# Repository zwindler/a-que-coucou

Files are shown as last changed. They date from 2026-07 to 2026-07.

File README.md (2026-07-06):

# À que coucou !

> Une boîte à coucou qui détecte l'expression **"ah que coucou"** grâce à un modèle de wake word, actionne un servomoteur pour faire sortir un œuf, et joue le son "coucou !".

Inspirée du running gag des [Guignols de l'info](https://www.youtube.com/watch?v=vwc_aIZz_1g) où Johnny Hallyday présentait une boîte mystérieuse à PPDA.

## Principe

1. Un microphone écoute en permanence l'environnement sonore
2. Quand la phrase **"ah que coucou"** est détectée, la boîte se déclenche
3. Un œuf monte mécaniquement hors de la boîte via un pignon-crémaillère
4. Le son *"coucou !"* est joué via un haut-parleur
5. L'œuf redescend après quelques secondes

Le tout fonctionne de manière autonome sur un Raspberry Pi, sans connexion internet, avec une latence inférieure à 500ms.

## Matériel

| Composant | Usage |
|---|---|
| Raspberry Pi 5 | Plateforme principale |
| Servo TowerPro SG90 (GPIO13 PWM) | Actionne l'œuf |
| Micro INMP441 I2S | Capture audio |
| Ampli MAX98357A I2S | Sortie audio |
| Haut-parleur 4Ω 3W | Diffusion sonore |
| Boîte + œuf imprimés en 3D | Habillage et mécanisme |
| Breadboard 170pts | Partage bus I2S |
| Câbles Dupont F-F et M-F | Câblage |

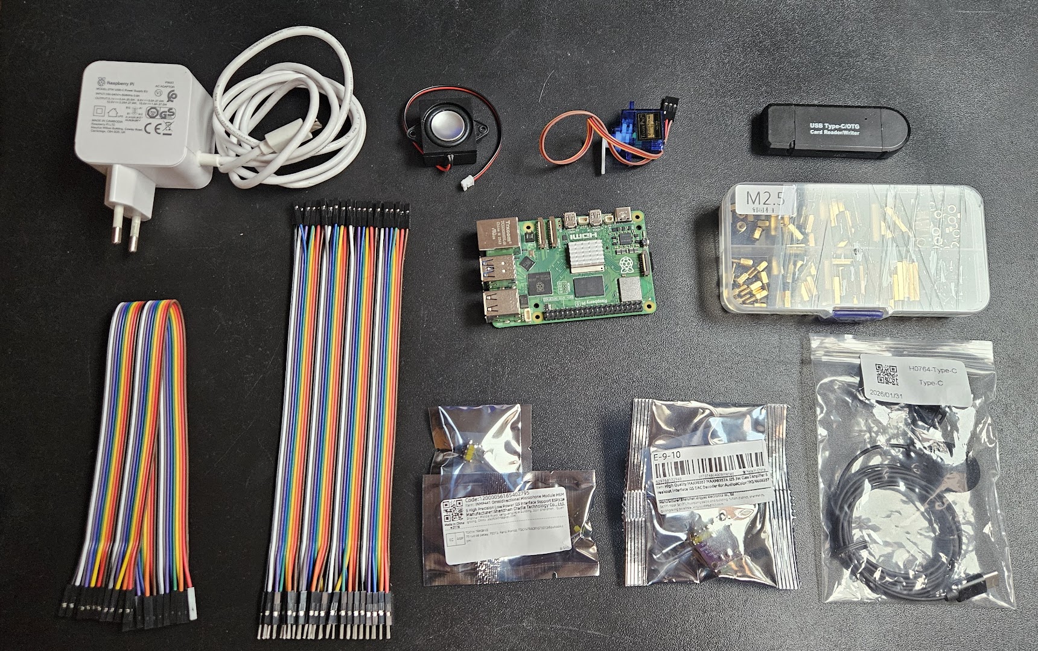
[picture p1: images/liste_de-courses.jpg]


Coût total du projet : **30-40 €** (hors RPi 5 & imprimante 3D).

## Architecture

```
aquecoucou.py           # Orchestrateur : détection -> servo -> son
wakeword.py             # Module de détection openWakeWord
├── setup.sh            # Installation complète RPi (apt, pip, config.txt, systemd)
├── deploy.sh           # Déploiement vers le RPi (tar + ssh)
└── deploy/
    └── aquecoucou.service  # Unité systemd (démarrage automatique)

tests/                  # Scripts de diagnostic
├── test_servo.py       # Test servo SG90
├── test_audio.py       # Test lecture WAV
├── test_wakeword.py    # Test détection en temps réel (affichage scores)
└── test_mic.py         # Diagnostic micro (analyse RMS, static noise)

wakeword/               # Pipeline d'entraînement
├── train_wakeword.py   # Entraînement modèle openWakeWord
├── generate_tts.py     # Génération voix synthétiques (Coqui TTS)
├── Containerfile       # Container TTS
├── Containerfile.train # Container entraînement
└── output/             # Modèle ONNX entraîné

cad/                    # CAO (OpenSCAD)
├── base.scad / .stl    # Base de la boîte
├── box.scad / .stl     # Murs de la boîte
├── pinion.scad / .stl  # Pignon 40mm (axe SG90)
├── rack.scad / .stl    # Crémaillère 110mm
├── egg.scad / .stl     # Œuf
├── rail_bracket.scad / .stl  # Rail + support servo
└── aquecoucou.3mf      # Projet d'assemblage pour mon imprimante Bambu Labs

sounds/
└── boite_a_coucou.wav  # Son "coucou !" (à fournir, voir sounds/README.md)

images/                 # Photos et captures d'écran
```

## Câblage

Tout se branche sur le header GPIO 40 broches du Raspberry Pi 5. Les composants audio (micro + ampli) partagent le même bus I2S ; le servo est piloté en PWM matériel sur GPIO13.

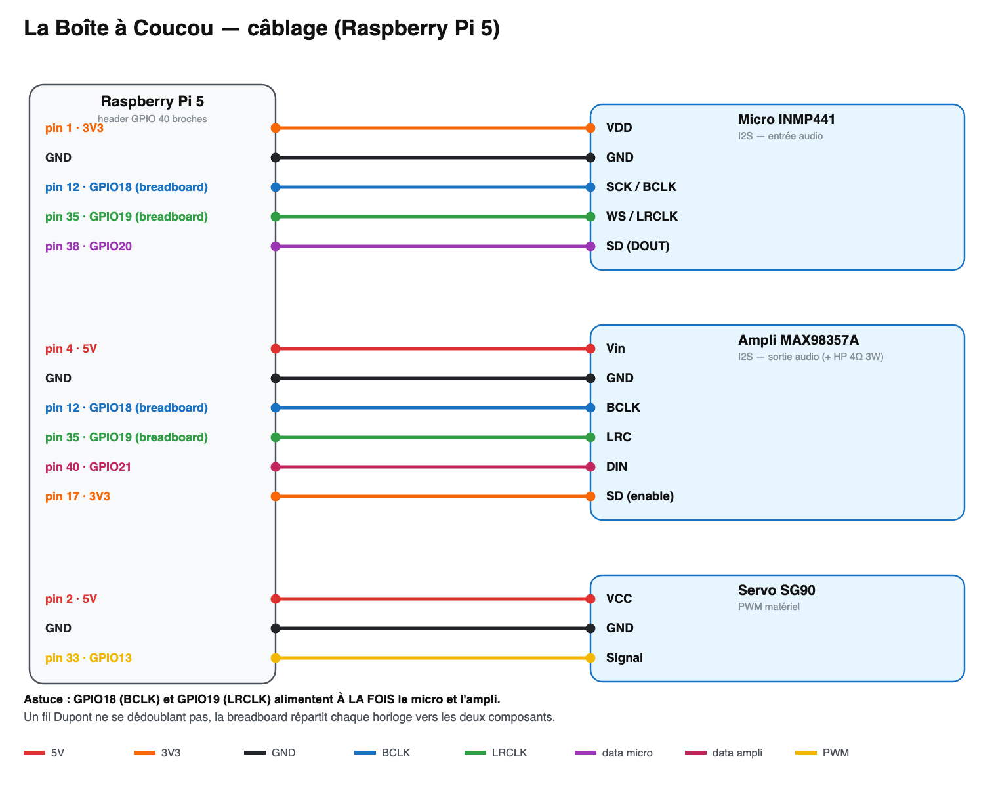
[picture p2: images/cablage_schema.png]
Schéma de câblage


Et la position physique des broches sur le header (pour ne pas se tromper au branchement) :

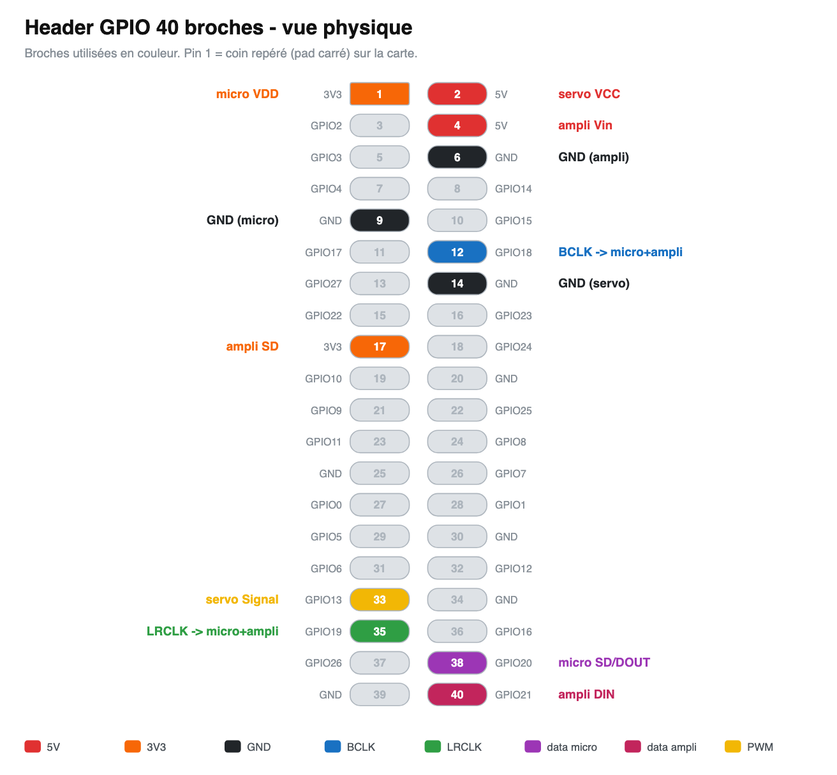
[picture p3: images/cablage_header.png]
Header GPIO 40 broches - broches utilisées en couleur


Le détail broche par broche (à cocher pendant le branchement) :

| Composant | Broche | Broche RPi |
|---|---|---|
| **Servo SG90** | VCC | 5V (broche 2) |
| | GND | GND (broche 14) |
| | Signal | GPIO13 / PWM (broche 33) |
| **Micro INMP441** (I2S) | VDD | 3.3V (broche 1) |
| | GND | GND (broche 9) |
| | SCK (BCLK) | GPIO18 (broche 12), via breadboard |
| | WS (LRCLK) | GPIO19 (broche 35), via breadboard |
| | SD (DOUT) | GPIO20 (broche 38) |
| **Ampli MAX98357A** (I2S) | Vin | 5V (broche 4) |
| | GND | GND (broche 6) |
| | BCLK | GPIO18 (broche 12), via breadboard |
| | LRC | GPIO19 (broche 35), via breadboard |
| | DIN | GPIO21 (broche 40) |
| | SD | 3.3V (broche 17), pour activer la sortie |
| | Speaker + / - | Haut-parleur 4Ω 3W |

Si votre module INMP441 a une broche `L/R`, reliez-la à GND (canal gauche).

**Le point important** : les deux horloges I2S, BCLK (GPIO18) et LRCLK (GPIO19), doivent être reliées **à la fois** au micro et à l'ampli. Un câble Dupont ne se dédoublant pas, on passe par la breadboard pour répartir chacune de ces deux lignes vers les deux composants.

Les overlays nécessaires (`googlevoicehat-soundcard` pour l'I2S et `pwm-2chan` pour le servo) sont ajoutés dans `/boot/firmware/config.txt` par `setup.sh`.

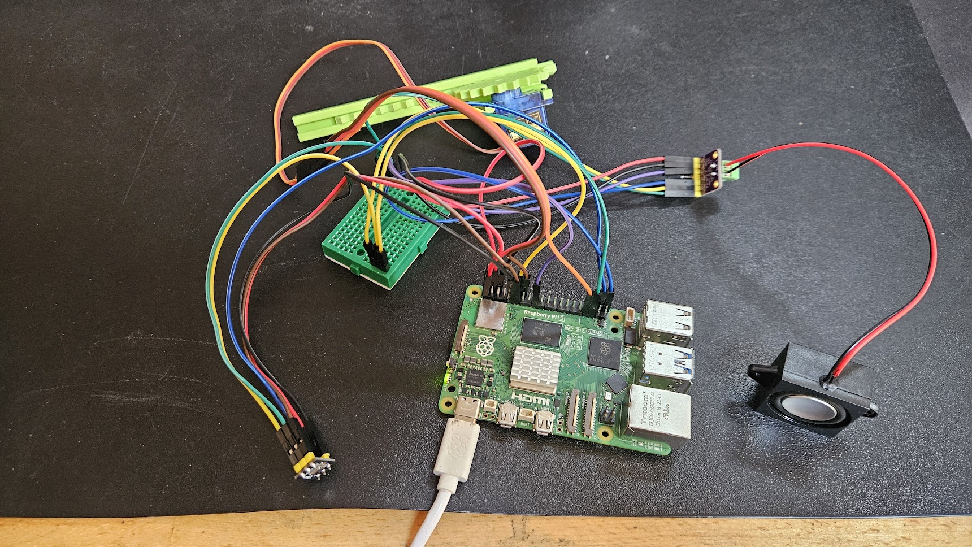
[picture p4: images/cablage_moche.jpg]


## Mécanisme (pignon-crémaillère)

Le servo ne fait qu'un mouvement semi-circulaire ; pour faire sortir l'œuf **tout droit**, un pignon fixé sur son axe entraîne une crémaillère, convertissant la rotation en translation verticale. Les pièces sont paramétriques en OpenSCAD (`cad/pinion.scad`, `cad/rack.scad`).

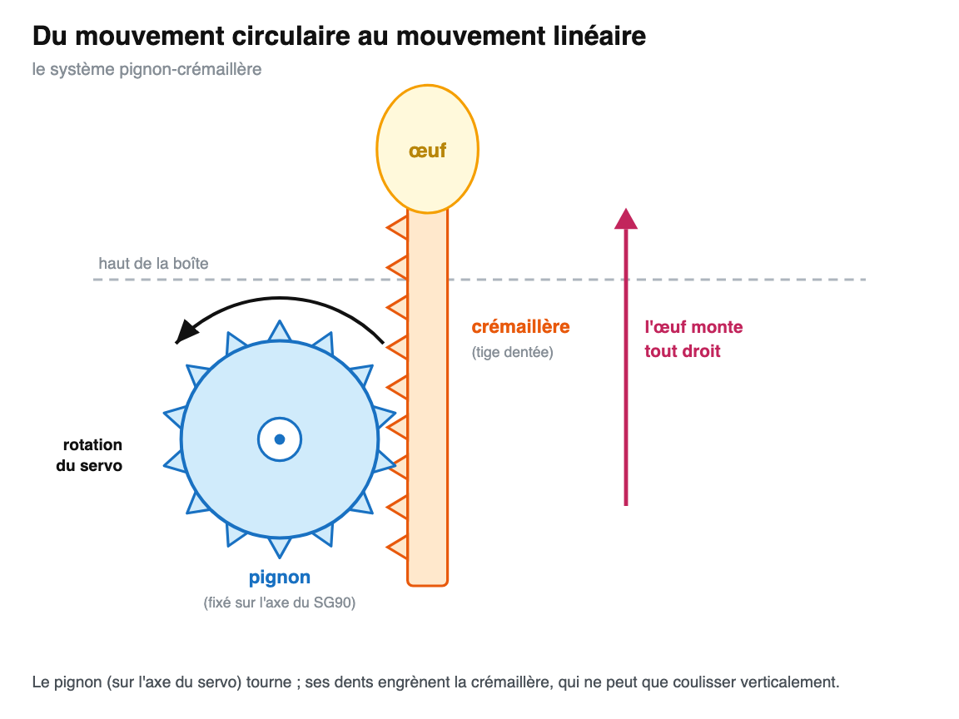
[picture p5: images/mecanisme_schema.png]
Principe pignon-crémaillère : la rotation du servo est convertie en montée verticale de l'œuf


## Installation

```bash
# Sur le Raspberry Pi, tout-en-un
./setup.sh
```

`setup.sh` installe les dépendances système, crée le venv, installe les paquets Python, configure `/boot/firmware/config.txt` (désactive l'audio BCM, ajoute les overlays I2S et PWM), et installe le service systemd.

## Utilisation

```bash
python aquecoucou.py [--device 0] [--threshold 0.3] [--cooldown 5] [--model chemin]
```

Le service systemd démarre automatiquement au boot. Déployer une nouvelle version :

```bash
./deploy.sh pi@raspberrypi.local
```

## Entraînement du modèle

Le modèle de wake word "ah que coucou" est entraîné à partir de voix synthétiques générées par Coqui TTS (XTTS v2), avec augmentation audio et exemples négatifs.

En amont, chaque extrait sonore est transformé en mel-spectrogramme (représentation temps-fréquence) avant d'alimenter le modèle :

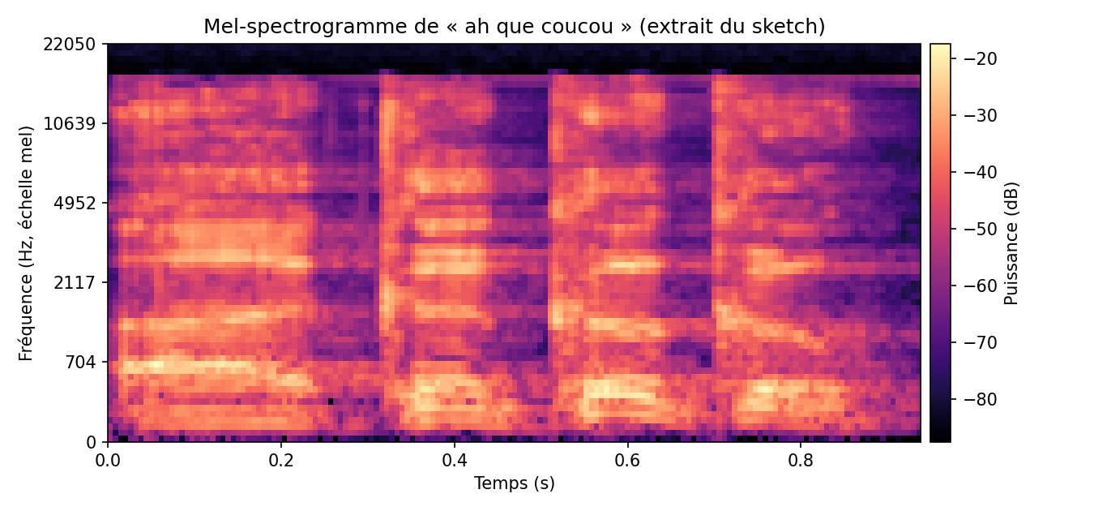
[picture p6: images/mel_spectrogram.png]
Mel-spectrogramme de « ah que coucou »


```bash
# Génération des voix TTS (nécessite GPU)
cd wakeword
podman build -f Containerfile -t aquecoucou-tts .
podman run --rm --device nvidia.com/gpu=all \
  -v ./output:/app/output:z aquecoucou-tts

# Entraînement du modèle (GPU recommandé)
podman build -f Containerfile.train -t aquecoucou-train .
podman run --rm --device nvidia.com/gpu=all \
  -v ./output:/app/output:z aquecoucou-train
```

> **Note** : la génération TTS a besoin de voix de référence (fichiers WAV montés dans le conteneur via `generate_tts.py --references-dir`). Celles utilisées ici sont des voix personnelles, non distribuées avec le projet : pour régénérer les données, fournissez les vôtres. Le modèle pré-entraîné (`wakeword/output/ah_que_coucou.onnx`) est de toute façon inclus et prêt à l'emploi.

## Au-delà du code

Ce projet est né d'une idée transgénérationnelle père-fils. Le père, électronicien, devait s'occuper de la partie mécanique ; le fils (moi) de la partie logicielle. Un premier prototype fonctionnel a vu le jour en 2021 avec Snowboy, avant qu'un deuil dans la famille ne mette le projet en pause. Cinq ans plus tard, en 2026, le projet a été relancé avec les technologies actuelles : openWakeWord pour la détection, un RPi 5 comme cerveau, et une mécanique imprimée en 3D.

## Licence

MPL 2.0

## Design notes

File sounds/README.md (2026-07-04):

# Son de la boîte

Placez ici le fichier `boite_a_coucou.wav` joué au déclenchement.

Le son original du sketch des Guignols de l'info est protégé par le droit
d'auteur et n'est donc pas distribué avec ce projet. Fournissez votre propre
enregistrement (n'importe quel WAV convient, idéalement court).

Format utilisé pour le prototype : WAV 44100 Hz, 16 bits, stéréo.
Le chemin attendu par le code est `sounds/boite_a_coucou.wav`
(voir `play_sound()` dans `aquecoucou.py`).

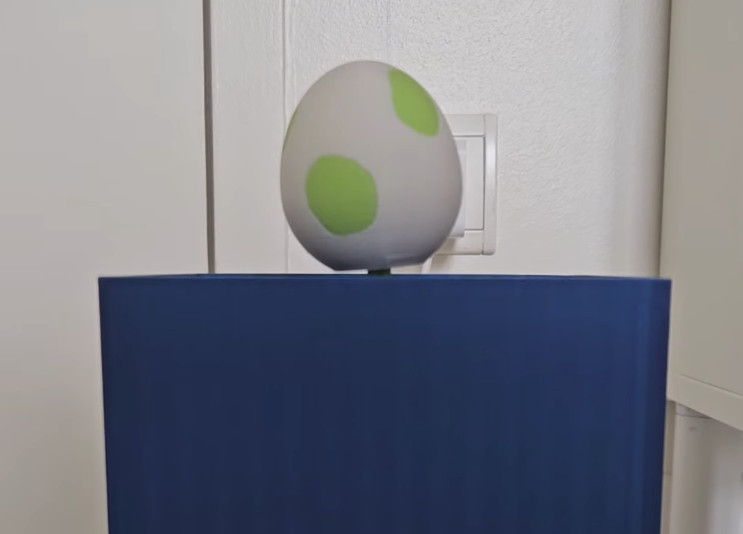
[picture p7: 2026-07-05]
images/capture_video.png

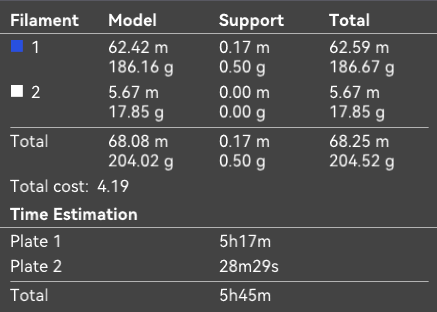
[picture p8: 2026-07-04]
images/filament_boite_coucou.png

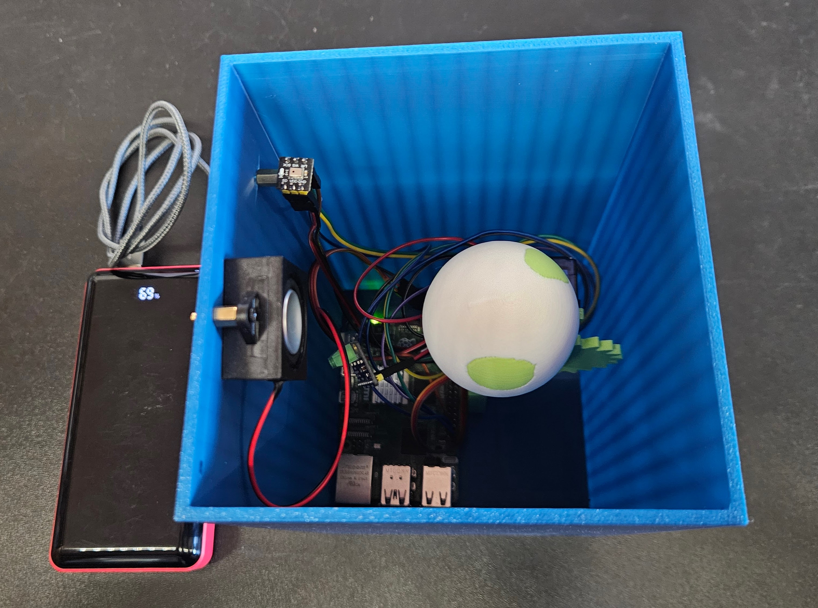
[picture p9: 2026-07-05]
images/boite_vue_den_haut.jpg

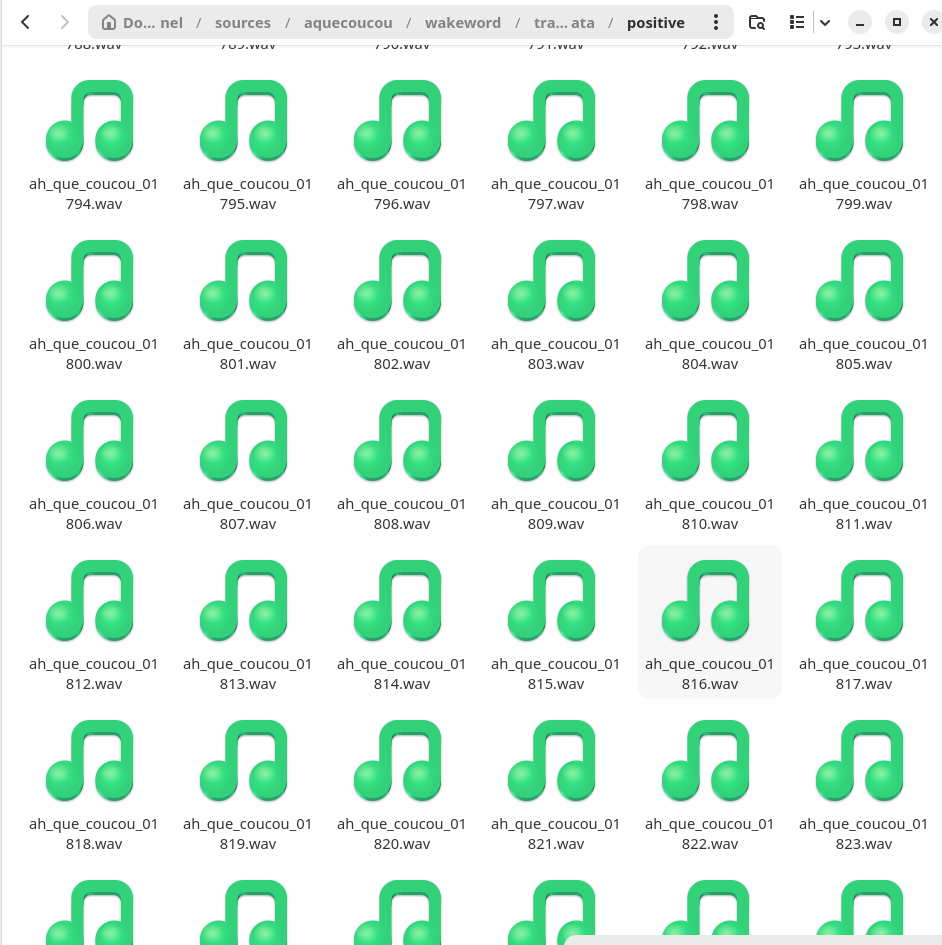
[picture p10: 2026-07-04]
images/generer_tts_aquecoucou.png

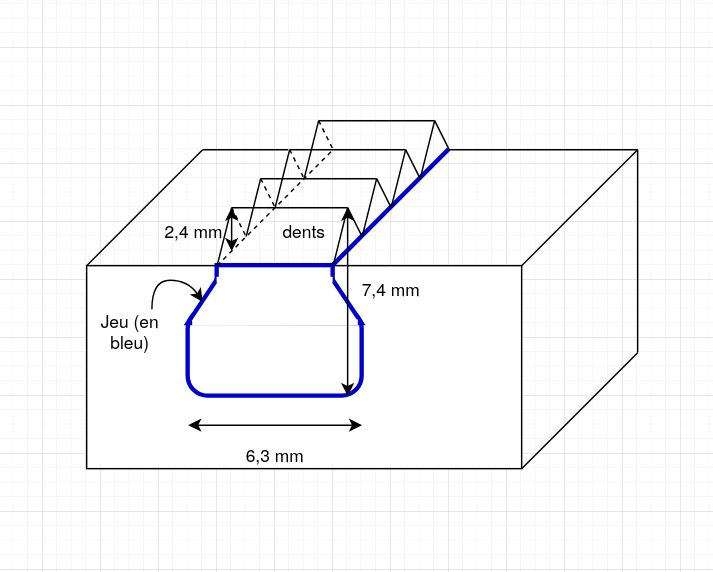
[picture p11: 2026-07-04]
images/rack.png

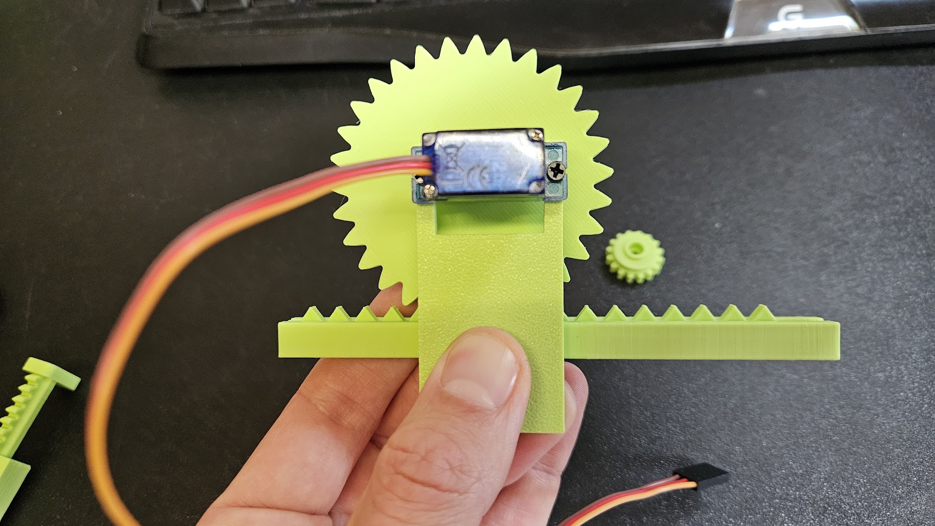
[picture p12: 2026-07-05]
images/pinion_rack.jpg

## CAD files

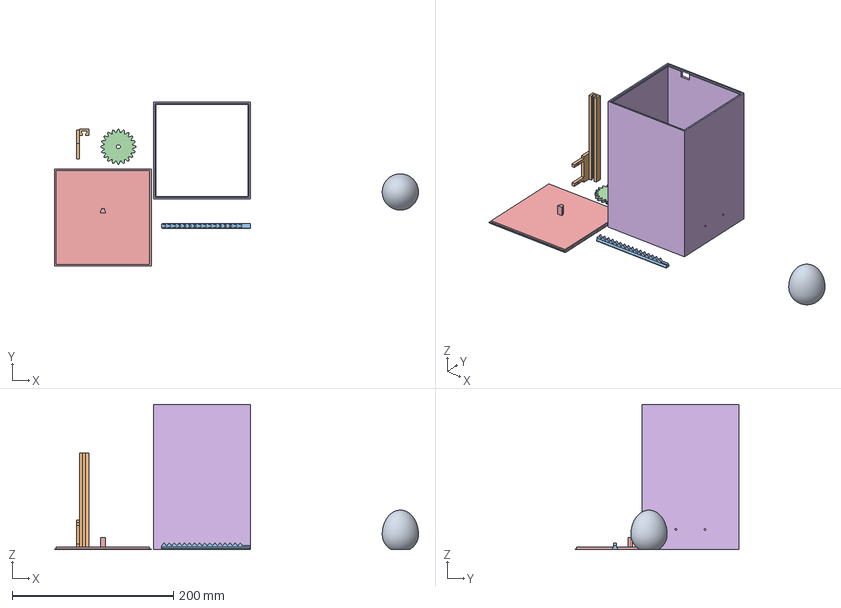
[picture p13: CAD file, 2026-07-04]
cad/aquecoucou.3mf
451.0 x 202.9 x 180.0 mm
egg.stl
rail_bracket.stl
rack.stl
pinion.stl
base.stl
box.stl

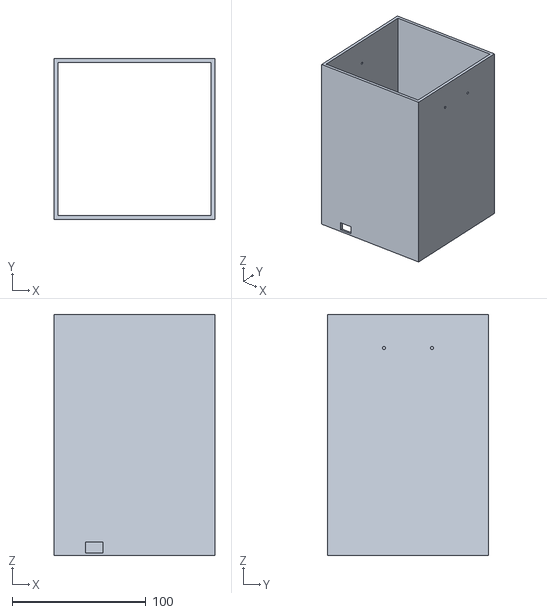
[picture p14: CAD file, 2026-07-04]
cad/box.stl
120.0 x 120.0 x 180.0

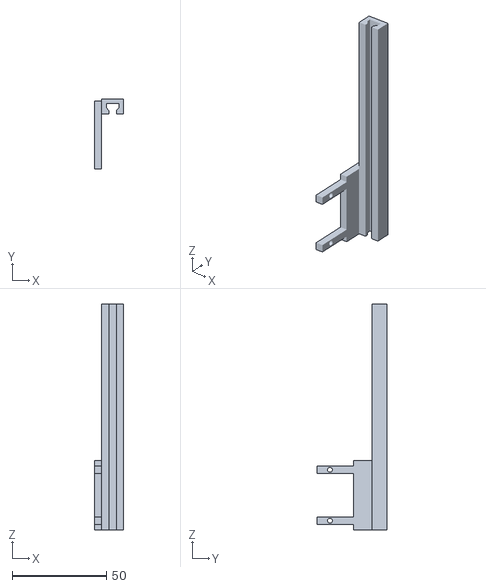
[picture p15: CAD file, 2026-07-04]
cad/rail_bracket.stl
15.6 x 37.2 x 120.0

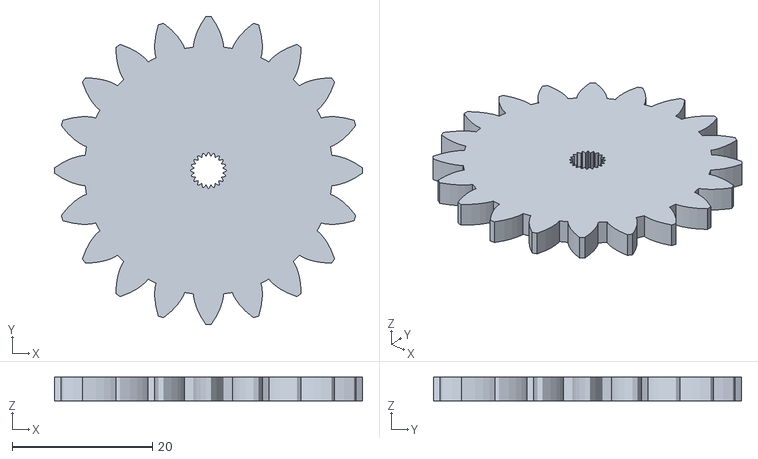
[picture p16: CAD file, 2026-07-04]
cad/pinion.stl
44.0 x 44.0 x 3.40

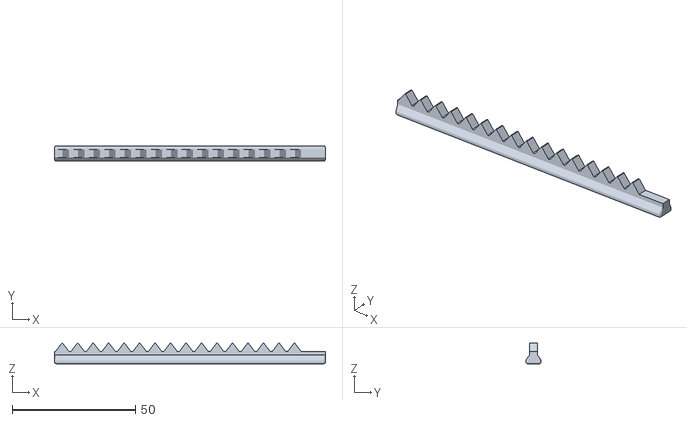
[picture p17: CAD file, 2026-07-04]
cad/rack.stl
110.0 x 6.27 x 8.39

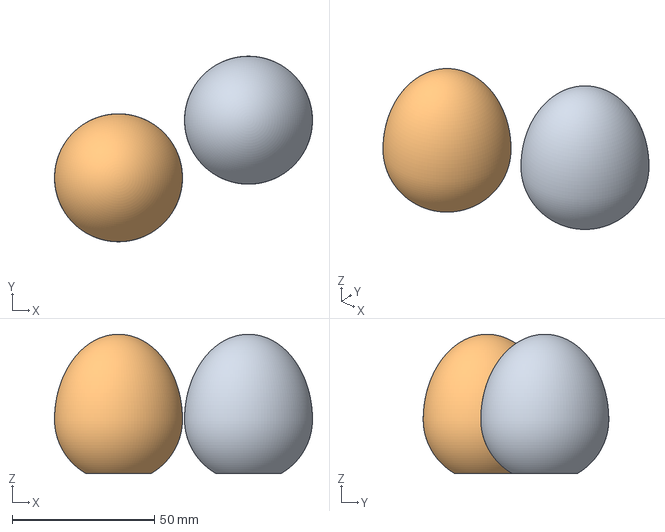
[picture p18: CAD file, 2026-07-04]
cad/egg_AMS_option.3mf
90.7 x 65.2 x 49.0 mm
egg.stl x 2

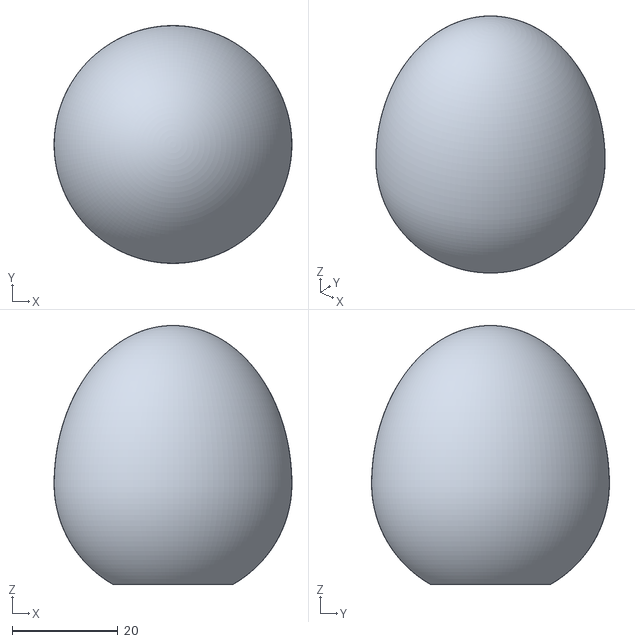
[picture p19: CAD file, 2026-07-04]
cad/egg.stl
45.0 x 45.0 x 49.0

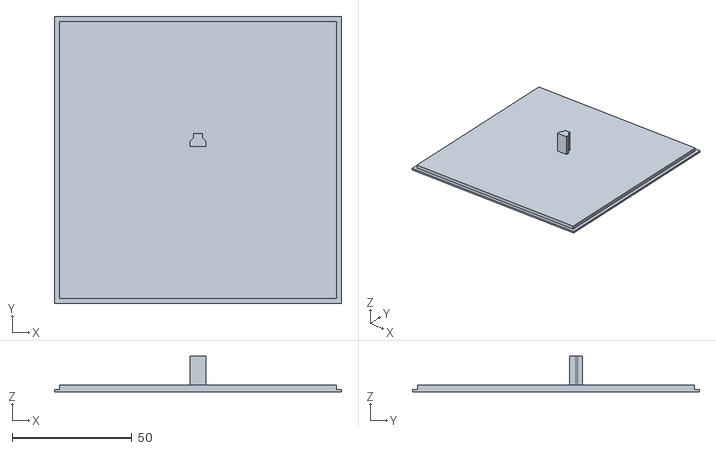
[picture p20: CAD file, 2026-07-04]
cad/base.stl
120.0 x 120.0 x 15.0

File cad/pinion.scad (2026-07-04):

// Pignon pour rack and pinion - La Boîte à Coucou
// Compatible axe SG90 spline cannelé 4.7mm
//
// Paramètres clés :
//   gear_module   : taille des dents (mm) - doit être identique dans rack.scad
//   num_teeth     : nombre de dents - détermine le diamètre primitif
//   thickness     : épaisseur du pignon
//   spline_d      : diamètre de l'alésage spline (légèrement sous 4.7mm pour serrage)

include <MCAD/involute_gears.scad>

// --- Paramètres engrenage ---
gear_module     = 2;           // module standard (taille des dents)
circular_pitch  = gear_module * 180;  // MCAD utilise circular_pitch en "degrés × mm"
num_teeth       = 20;          // diam primitif = 20 × 2 = 40mm -> course = 20π ≈ 63mm
pressure_angle  = 28;          // défaut MCAD, bien pour impression 3D

// --- Géométrie du pignon ---
// gear_thickness  : épaisseur de la couronne dentée
// rim_thickness   : épaisseur du disque (= hub_h pour que le disque soit plein sur toute la hauteur)
// hub_thickness   : hauteur du moyeu central (dépasse pour serrer l'axe)
thickness       = 3.4;         // épaisseur = largeur tige crémaillère (stem_w)
hub_h           = 3.4;         // hauteur totale alignée sur la crémaillère
hub_d           = 10;          // diamètre extérieur du moyeu

// --- Alésage axe SG90 ---
// Profil spline extrait du STL de référence MicroServo_9g_Gear_Base_V4_-_Final_Denis.stl
// 280 points, rayon min ~2.11mm (creux cannelure), rayon max ~2.64mm (sommet cannelure)
spline_profile = [
  [-2.637, -0.008], [-2.637, -0.024], [-2.462, -0.148], [-2.274, -0.241],
  [-2.139, -0.282], [-2.124, -0.3],   [-2.114, -0.322], [-2.11, -0.346],
  [-2.112, -0.371], [-2.122, -0.393], [-2.237, -0.474], [-2.382, -0.615],
  [-2.516, -0.792], [-2.511, -0.807], [-2.506, -0.823], [-2.501, -0.838],
  [-2.312, -0.897], [-2.089, -0.932], [-1.947, -0.929], [-1.927, -0.942],
  [-1.91, -0.96],   [-1.899, -0.981], [-1.895, -1.005], [-1.896, -1.029],
  [-1.981, -1.142], [-2.072, -1.313], [-2.148, -1.531], [-2.138, -1.544],
  [-2.129, -1.557], [-2.119, -1.57],  [-1.853, -1.561], [-1.698, -1.532],
  [-1.565, -1.485], [-1.541, -1.491], [-1.52, -1.503],  [-1.503, -1.52],
  [-1.491, -1.541], [-1.485, -1.565], [-1.532, -1.698], [-1.561, -1.853],
  [-1.57, -2.119],  [-1.557, -2.129], [-1.544, -2.138], [-1.531, -2.148],
  [-1.313, -2.072], [-1.142, -1.981], [-1.029, -1.896], [-1.005, -1.895],
  [-0.981, -1.899], [-0.96, -1.91],   [-0.942, -1.927], [-0.929, -1.947],
  [-0.932, -2.089], [-0.897, -2.312], [-0.838, -2.501], [-0.823, -2.506],
  [-0.807, -2.511], [-0.792, -2.516], [-0.615, -2.382], [-0.474, -2.237],
  [-0.393, -2.122], [-0.371, -2.112], [-0.346, -2.11],  [-0.322, -2.114],
  [-0.3, -2.124],   [-0.282, -2.139], [-0.241, -2.274], [-0.148, -2.462],
  [-0.024, -2.637], [-0.008, -2.637], [0.008, -2.637],  [0.024, -2.637],
  [0.148, -2.462],  [0.241, -2.274],  [0.282, -2.139],  [0.3, -2.124],
  [0.322, -2.114],  [0.346, -2.11],   [0.371, -2.112],  [0.393, -2.122],
  [0.474, -2.237],  [0.615, -2.382],  [0.792, -2.516],  [0.807, -2.511],
  [0.823, -2.506],  [0.838, -2.501],  [0.897, -2.312],  [0.932, -2.089],
  [0.929, -1.947],  [0.942, -1.927],  [0.96, -1.91],    [0.981, -1.899],
  [1.005, -1.895],  [1.029, -1.896],  [1.142, -1.981],  [1.313, -2.072],
  [1.531, -2.148],  [1.544, -2.138],  [1.557, -2.129],  [1.57, -2.119],
  [1.561, -1.853],  [1.532, -1.698],  [1.485, -1.565],  [1.491, -1.541],
  [1.503, -1.52],   [1.52, -1.503],   [1.541, -1.491],  [1.565, -1.485],
  [1.698, -1.532],  [1.853, -1.561],  [2.119, -1.57],   [2.129, -1.557],
  [2.138, -1.544],  [2.148, -1.531],  [2.072, -1.313],  [1.981, -1.142],
  [1.896, -1.029],  [1.895, -1.005],  [1.899, -0.981],  [1.91, -0.96],
  [1.927, -0.942],  [1.947, -0.929],  [2.089, -0.932],  [2.312, -0.897],
  [2.501, -0.838],  [2.506, -0.823],  [2.511, -0.807],  [2.516, -0.792],
  [2.382, -0.615],  [2.237, -0.474],  [2.122, -0.393],  [2.112, -0.371],
  [2.11, -0.346],   [2.114, -0.322],  [2.124, -0.3],    [2.139, -0.282],
  [2.274, -0.241],  [2.462, -0.148],  [2.637, -0.024],  [2.637, -0.008],
  [2.637, 0.008],   [2.637, 0.024],   [2.462, 0.148],   [2.274, 0.241],
  [2.139, 0.282],   [2.124, 0.3],     [2.114, 0.322],   [2.11, 0.346],
  [2.112, 0.371],   [2.122, 0.393],   [2.237, 0.474],   [2.382, 0.615],
  [2.516, 0.792],   [2.511, 0.807],   [2.506, 0.823],   [2.501, 0.838],
  [2.312, 0.897],   [2.089, 0.932],   [1.947, 0.929],   [1.927, 0.942],
  [1.91, 0.96],     [1.899, 0.981],   [1.895, 1.005],   [1.896, 1.029],
  [1.981, 1.142],   [2.072, 1.313],   [2.148, 1.531],   [2.138, 1.544],
  [2.129, 1.557],   [2.119, 1.57],    [1.853, 1.561],   [1.698, 1.532],
  [1.565, 1.485],   [1.541, 1.491],   [1.52, 1.503],    [1.503, 1.52],
  [1.491, 1.541],   [1.485, 1.565],   [1.532, 1.698],   [1.561, 1.853],
  [1.57, 2.119],    [1.557, 2.129],   [1.544, 2.138],   [1.531, 2.148],
  [1.313, 2.072],   [1.142, 1.981],   [1.029, 1.896],   [1.005, 1.895],
  [0.981, 1.899],   [0.96, 1.91],     [0.942, 1.927],   [0.929, 1.947],
  [0.932, 2.089],   [0.897, 2.312],   [0.838, 2.501],   [0.823, 2.506],
  [0.807, 2.511],   [0.792, 2.516],   [0.615, 2.382],   [0.474, 2.237],
  [0.393, 2.122],   [0.371, 2.112],   [0.346, 2.11],    [0.322, 2.114],
  [0.3, 2.124],     [0.282, 2.139],   [0.241, 2.274],   [0.148, 2.462],
  [0.024, 2.637],   [0.008, 2.637],   [-0.008, 2.637],  [-0.024, 2.637],
  [-0.148, 2.462],  [-0.241, 2.274],  [-0.282, 2.139],  [-0.3, 2.124],
  [-0.322, 2.114],  [-0.346, 2.11],   [-0.371, 2.112],  [-0.393, 2.122],
  [-0.474, 2.237],  [-0.615, 2.382],  [-0.792, 2.516],  [-0.807, 2.511],
  [-0.823, 2.506],  [-0.838, 2.501],  [-0.897, 2.312],  [-0.932, 2.089],
  [-0.929, 1.947],  [-0.942, 1.927],  [-0.96, 1.91],    [-0.981, 1.899],
  [-1.005, 1.895],  [-1.029, 1.896],  [-1.142, 1.981],  [-1.313, 2.072],
  [-1.531, 2.148],  [-1.544, 2.138],  [-1.557, 2.129],  [-1.57, 2.119],
  [-1.561, 1.853],  [-1.532, 1.698],  [-1.485, 1.565],  [-1.491, 1.541],
  [-1.503, 1.52],   [-1.52, 1.503],   [-1.541, 1.491],  [-1.565, 1.485],
  [-1.698, 1.532],  [-1.853, 1.561],  [-2.119, 1.57],   [-2.129, 1.557],
  [-2.138, 1.544],  [-2.148, 1.531],  [-2.072, 1.313],  [-1.981, 1.142],
  [-1.896, 1.029],  [-1.895, 1.005],  [-1.899, 0.981],  [-1.91, 0.96],
  [-1.927, 0.942],  [-1.947, 0.929],  [-2.089, 0.932],  [-2.312, 0.897],
  [-2.501, 0.838],  [-2.506, 0.823],  [-2.511, 0.807],  [-2.516, 0.792],
  [-2.382, 0.615],  [-2.237, 0.474],  [-2.122, 0.393],  [-2.112, 0.371],
  [-2.11, 0.346],   [-2.114, 0.322],  [-2.124, 0.3],    [-2.139, 0.282],
  [-2.274, 0.241],  [-2.462, 0.148],  [-2.637, 0.024],  [-2.637, 0.008],
];

// --- Vis de serrage M2 (optionnel) ---
// Un trou M2 radial permet de bloquer le pignon avec une vis pointeau.
// Mettre à false si tu ne veux pas le perçage.
set_screw       = true;
set_screw_d     = 2.2;         // diamètre trou M2 (légèrement surdimensionné)

// --- Facteur de serrage de l'alésage spline ---
// 1.0 = taille originale (trop lâche à l'impression)
// Réduire pour serrer : chaque -0.05 enlève ~0.1mm sur le rayon
spline_scale    = 0.983;       // compense XY hole compensation +0.03mm du slicer

// =====================================================
// Pignon
// =====================================================

// Rayon primitif = num_teeth * gear_module / 2
pitch_radius = num_teeth * gear_module / 2;  // 20mm
// Rayon de la jante (fond des dents = pitch_radius - dedendum)
rim_radius   = pitch_radius - gear_module * 1.25;  // ~17.5mm

difference() {
    union() {
        // Dents involutes via MCAD - on désactive hub et rim internes
        // en les alignant sur gear_thickness pour éviter les volumes creux
        render()
        gear(
            number_of_teeth = num_teeth,
            circular_pitch  = circular_pitch,
            pressure_angle  = pressure_angle,
            gear_thickness  = hub_h,
            rim_thickness   = hub_h,
            hub_thickness   = hub_h,
            hub_diameter    = hub_d,
            bore_diameter   = 0.1  // alésage géré manuellement via spline_profile
        );

        // Disque plein qui comble le vide entre dents et moyeu
        cylinder(r = rim_radius, h = hub_h, $fn = 80);
    }

    // Alésage axe SG90 - profil spline scalé pour serrage
    translate([0, 0, -0.1])
    linear_extrude(height = hub_h + 0.2)
    scale([spline_scale, spline_scale, 1])
    polygon(spline_profile);

    // Vis de serrage radiale M2
    if (set_screw) {
        translate([hub_d / 2 + 1, 0, hub_h / 2])
        rotate([0, 90, 0])
        cylinder(d = set_screw_d, h = hub_d, $fn = 20);
    }
}

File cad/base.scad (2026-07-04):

// Base de la boîte - La Boîte à Coucou
//
// Vue de dessus (schéma utilisateur) :
//   Y+ = côté rail (haut du schéma)
//   Y- = côté Pi (bas du schéma) -> trou câble alimentation
//   X  = centré
//
// Assemblage :
//   - base plate avec rainure périphérique pour les murs (box.scad)
//   - languette mâle en T côté Y+, centrée en X :
//     profil identique à la crémaillère (rack.scad), jeu tight 0.1mm
//     s'insère dans le canal du rail_bracket par le bas
//
// PROTO validé à 50% (01/05/2026). Version finale : 120x120mm, languette 12mm
// ===================================================================

// -------------------------------------------------------------------
// Profil T intérieur du rail (identique à rail_bracket.scad)
// On reproduit le profil avec jeu tight pour que la languette s'emboîte
// -------------------------------------------------------------------
rb_head_w  = 6.3;
rb_head_h  = 2.0;
rb_taper_h = 1.5;
rb_stem_w  = 3.4;
rb_stem_h  = 1.5;
rb_cl      = 0.20;   // jeu glissant interne du rail

// Dimensions intérieures du canal (ce dans quoi on doit rentrer)
canal_head_w = rb_head_w + 2*rb_cl;
canal_stem_w = rb_stem_w + 2*rb_cl;
canal_head_h = rb_head_h + rb_cl;
canal_taper  = rb_taper_h;
canal_stem_h = rb_stem_h + rb_cl;

cl_tight     = 0.05;   // jeu tight languette dans canal

// Languette mâle : légèrement plus petite que le canal
tongue_head_w = canal_head_w - 2*cl_tight;
tongue_stem_w = canal_stem_w - 2*cl_tight;
tongue_head_h = canal_head_h - cl_tight;
tongue_taper  = canal_taper;
tongue_stem_h = canal_stem_h - cl_tight;
tongue_h      = 12;   // hauteur de la languette réduite (évite contact avec bas du rail)

// -------------------------------------------------------------------
// Dimensions base (proto 50%)
// -------------------------------------------------------------------
proto    = 1.0;

base_x   = 120 * proto;   // 120mm
base_y   = 120 * proto;   // 120mm
base_z   = 3;

groove_w = 2;  // pas de jeu - filament bien calibré
groove_d = 2;
wall_t   = 3;

cable_d  = 10;
cable_x  = base_x / 2;

// -------------------------------------------------------------------
// Module languette mâle en T (section 2D, profil crémaillère)
// -------------------------------------------------------------------
module tongue_2d() {
    polygon([
        // tige (partie fine, face avant Y=0)
        [-tongue_stem_w/2, 0                                        ],
        [ tongue_stem_w/2, 0                                        ],
        // trapèze
        [ tongue_stem_w/2, tongue_stem_h                            ],
        [ tongue_head_w/2, tongue_stem_h + tongue_taper             ],
        // base large
        [ tongue_head_w/2, tongue_stem_h + tongue_taper + tongue_head_h ],
        [-tongue_head_w/2, tongue_stem_h + tongue_taper + tongue_head_h ],
        [-tongue_head_w/2, tongue_stem_h + tongue_taper             ],
        [-tongue_stem_w/2, tongue_stem_h                            ],
    ]);
}

// -------------------------------------------------------------------
// Base
// -------------------------------------------------------------------
difference() {
    union() {
        // Dalle principale
        cube([base_x, base_y, base_z]);

        // Languette mâle - centrée en X, côté Y+, décalée de wall_t du bord
        // S'insère vers le haut dans le canal du rail_bracket
        // Miroir Y : tête large côté Y-, tige fine côté Y+ (câbles dégagés du côté pignon/crémaillère)
        translate([base_x/2, base_y - wall_t - 46, base_z])
        mirror([0,1,0])
        linear_extrude(height = tongue_h)
        tongue_2d();
    }

    // Rainure périphérique collée au bord extérieur
    translate([0, 0, base_z - groove_d])
    difference() {
        cube([base_x, base_y, groove_d + 0.1]);
        translate([groove_w, groove_w, -0.1])
        cube([base_x - 2*groove_w, base_y - 2*groove_w, groove_d + 0.3]);
    }
}

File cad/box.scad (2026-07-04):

// Murs de la boîte - La Boîte à Coucou
//
// Tube carré monobloc (4 murs solidaires), ouvert en haut et en bas.
// Tenon 2x2mm en bas qui s'insère dans la rainure périphérique de base.scad.
//
// PoC : hauteur 20mm, pas de trou, pas de grille.
// Version finale : ajuster wall_h, ajouter trou câble Ø10mm côté Y-.
// ===================================================================

base_x   = 120;
base_y   = 120;
wall_t   = 3;    // épaisseur des murs
wall_h   = 180;  // hauteur finale 18cm

// Tenon correspondant à la rainure de base.scad
// groove_w=2, groove_d=2, collée au bord extérieur
tenon_w  = 2;
tenon_h  = 2;
cl       = 0;  // pas de jeu - filament bien calibré

// Dimensions réelles avec jeu
box_x    = base_x - 2*cl;
box_y    = base_y - 2*cl;

// Trou câble USB-C - mur Y- (côté Pi), centré en X
// Connecteur RPi5 USB-C : 7x12mm -> trou 8x13mm (1mm jeu)
usbc_w   = 13;   // largeur trou (axe X)
usbc_h   = 8;    // hauteur trou (axe Z)
usbc_z   = 2;    // distance du bas

// Trous haut-parleur - mur X+ (mur droit vu de la face USB-C), centrés en Y
spk_d    = 2.5;  // Ø M2.5
spk_z    = wall_h - 25;  // à 25mm du haut
spk_entraxe = 36;

// Trou micro - mur X- (mur gauche vu de la face USB-C), centré en Y, même hauteur que speaker
mic_d    = 2.5;  // Ø M2.5

// groove_w=2mm de chaque côté -> ouverture rainure = 120 - 2*2 = 116mm
// Le tenon doit faire < 116mm en extérieur -> 116 - 2*cl
groove_w = 2;
tenon_ext = base_x - 2*groove_w - 2*cl;  // extérieur du tenon = 115.6mm avec cl=0.20

// -------------------------------------------------------------------
// Murs : tube carré = cube plein - intérieur
// -------------------------------------------------------------------
difference() {
    // Tube plein - exactement 120x120mm
    cube([base_x, base_y, wall_h]);

    // Évidement intérieur
    translate([wall_t, wall_t, -0.1])
    cube([base_x - 2*wall_t, base_y - 2*wall_t, wall_h + 0.2]);

    // Évidement tenon : retire le bas pour que le tenon fasse tenon_ext en extérieur
    // offset de chaque côté = (base_x - tenon_ext) / 2 = groove_w + cl
    translate([groove_w + cl, groove_w + cl, -0.1])
    cube([tenon_ext, tenon_ext, tenon_h + 0.1]);

    // Trou câble USB-C - mur Y- (face avant), décalé 30mm à gauche du centre
    translate([base_x/2 - usbc_w/2 - 30, -0.1, usbc_z])
    cube([usbc_w, wall_t + 0.2, usbc_h]);

    // Trous fixation haut-parleur - mur X+, entraxe 36mm, centrés en Y
    for (dy = [-spk_entraxe/2, spk_entraxe/2])
    translate([base_x - wall_t - 0.1, base_y/2 + dy, spk_z])
    rotate([0, 90, 0])
    cylinder(d=spk_d, h=wall_t + 0.2, $fn=16);

    // Trou fixation micro - mur X-, centré en Y, même hauteur que speaker
    translate([-0.1, base_y/2, spk_z])
    rotate([0, 90, 0])
    cylinder(d=mic_d, h=wall_t + 0.2, $fn=16);
}

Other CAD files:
cad/egg.scad
cad/rack.scad
cad/rail_bracket.scad

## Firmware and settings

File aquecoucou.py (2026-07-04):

#!/usr/bin/env python3
"""
La Boîte à Coucou - orchestrateur principal.

Détecte "ah que coucou" via le micro, monte l'œuf avec le servo,
joue le son, puis redescend l'œuf.

Usage :
    python3 aquecoucou.py
    python3 aquecoucou.py --device 0 --threshold 0.6

Variables d'environnement (optionnelles) :
    SERVO_HIGH   duty cycle position haute / œuf sorti  (défaut: 0.025)
    SERVO_LOW    duty cycle position basse / repos       (défaut: 0.130)
    APLAY_ARGS   arguments aplay                        (défaut: -D plughw:0,0)
"""

import argparse
import os
import signal
import subprocess
import sys
import time
from pathlib import Path

SOUNDS_DIR = Path(__file__).parent / "sounds"
SERVO_HIGH = float(os.environ.get("SERVO_HIGH", "0.025"))
SERVO_LOW  = float(os.environ.get("SERVO_LOW",  "0.130"))
APLAY_ARGS = os.environ.get("APLAY_ARGS", "-D plughw:0,0").split()

PWM_CHIP    = "/sys/class/pwm/pwmchip0"
PWM_CHANNEL = "pwm1"  # GPIO13 = pwmchip0/pwm1
PWM_PERIOD  = 20_000_000  # 20ms = 50Hz


def servo_write(path, value):
    with open(path, "w") as f:
        f.write(str(value))


def servo_duty(duty_cycle):
    path = f"{PWM_CHIP}/{PWM_CHANNEL}/duty_cycle"
    servo_write(path, int(duty_cycle * PWM_PERIOD))


def servo_setup():
    pwm_path = f"{PWM_CHIP}/{PWM_CHANNEL}"
    if not os.path.exists(pwm_path):
        servo_write(f"{PWM_CHIP}/export", 1)
        time.sleep(0.1)
    servo_write(f"{pwm_path}/period", PWM_PERIOD)
    servo_duty(SERVO_LOW)
    servo_write(f"{pwm_path}/enable", 1)


def servo_teardown():
    servo_duty(SERVO_LOW)
    servo_write(f"{PWM_CHIP}/{PWM_CHANNEL}/enable", 0)


def play_sound():
    sound = SOUNDS_DIR / "boite_a_coucou.wav"
    subprocess.run(["/usr/bin/aplay"] + APLAY_ARGS + [str(sound)], check=True)


def trigger(score):
    print(f"Déclenché ! score={score:.4f}")

    servo_duty(SERVO_HIGH)
    time.sleep(0.25)   # laisse le servo atteindre la position haute

    try:
        play_sound()   # bloquant - redescend seulement quand le son est fini
    except Exception as e:
        print(f"Erreur son : {e}")
    finally:
        time.sleep(0.35)
        servo_duty(SERVO_LOW)


def main():
    parser = argparse.ArgumentParser()
    parser.add_argument("--device",    default="0")
    parser.add_argument("--threshold", type=float, default=0.5)
    parser.add_argument("--cooldown",  type=float, default=3.0)
    parser.add_argument("--model",     default=None)
    args = parser.parse_args()

    servo_setup()

    def shutdown(sig, frame):
        print("\nArrêt...")
        servo_teardown()
        sys.exit(0)

    signal.signal(signal.SIGTERM, shutdown)
    signal.signal(signal.SIGINT,  shutdown)

    from wakeword import listen
    kwargs = dict(threshold=args.threshold, cooldown=args.cooldown, device=args.device)
    if args.model:
        kwargs["model_path"] = args.model
    listen(trigger, **kwargs)


if __name__ == "__main__":
    main()

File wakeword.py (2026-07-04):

#!/usr/bin/env python3
"""
Détection du mot-clé "ah que coucou" via openWakeWord.

Écoute le microphone en continu. Quand le mot-clé est détecté,
appelle le callback fourni avec le score de confiance.

Usage autonome (test) :
    python3 wakeword.py
    python3 wakeword.py --threshold 0.7 --device 0
"""

import argparse
import os
import sys
import time
import warnings
from pathlib import Path

import numpy as np
import sounddevice as sd
from scipy import signal as scipy_signal

os.environ.setdefault("ORT_LOGGING_LEVEL", "3")
warnings.filterwarnings("ignore", message=".*CUDAExecutionProvider.*")

from openwakeword.model import Model

MODEL_PATH = Path(__file__).parent / "wakeword" / "output" / "ah_que_coucou.onnx"
SAMPLE_RATE = 16000
CHUNK = 1280  # 80ms @ 16kHz, taille requise par openWakeWord


def listen(callback, model_path=MODEL_PATH, threshold=0.5, cooldown=3.0, device=None):
    device_id = int(device) if device is not None and str(device).isdigit() else device
    try:
        device_info = sd.query_devices(device_id if device_id is not None else sd.default.device)
    except Exception as e:
        print(f"Erreur device audio : {e}", file=sys.stderr)
        sys.exit(1)

    native_rate = int(device_info["default_samplerate"])
    capture_chunk = int(CHUNK * native_rate / SAMPLE_RATE) if native_rate != SAMPLE_RATE else CHUNK

    print(f"Micro : {device_info['name']} @ {native_rate} Hz", file=sys.stderr)
    if native_rate != SAMPLE_RATE:
        print(f"Resampling {native_rate} -> {SAMPLE_RATE} Hz", file=sys.stderr)

    if not Path(model_path).exists():
        print(f"Modèle introuvable : {model_path}", file=sys.stderr)
        sys.exit(1)

    model = Model(wakeword_model_paths=[str(model_path)])
    print("Écoute en cours...", file=sys.stderr)

    last_detection = 0.0

    def audio_callback(indata, frames, time_info, status):
        nonlocal last_detection
        if status:
            print(f"Audio status : {status}", file=sys.stderr)

        mono = indata[:, 0]
        if native_rate != SAMPLE_RATE:
            mono = scipy_signal.resample_poly(mono, SAMPLE_RATE, native_rate)

        audio = (mono * 32768).astype(np.int16)
        score = model.predict(audio).get("ah_que_coucou", 0)

        now = time.monotonic()
        if score >= threshold and (now - last_detection) >= cooldown:
            last_detection = now
            callback(score)

    with sd.InputStream(
        samplerate=native_rate,
        channels=1,
        dtype="float32",
        blocksize=capture_chunk,
        device=device_id,
        callback=audio_callback,
    ):
        try:
            while True:
                sd.sleep(100)
        except KeyboardInterrupt:
            pass


if __name__ == "__main__":
    parser = argparse.ArgumentParser()
    parser.add_argument("--model", default=str(MODEL_PATH))
    parser.add_argument("--threshold", type=float, default=0.5)
    parser.add_argument("--cooldown", type=float, default=3.0)
    parser.add_argument("--device", default="0")
    args = parser.parse_args()

    def on_detection(score):
        print(f"Détecté ! score={score:.4f}")

    listen(on_detection, args.model, args.threshold, args.cooldown, args.device)

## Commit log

2026-07-04 chore: add images and add missing wiring infos
2026-07-05 Add schema for wiring
